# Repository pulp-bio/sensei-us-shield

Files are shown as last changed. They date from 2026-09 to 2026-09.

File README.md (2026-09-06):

# WULPUS PRO Shield for BioGAP

**Wearable, ultra-low-power ultrasound acquisition for the BioGAP-Ultra platform**  
Initial hardware and firmware release: **v1.0.0**

<p align="center">
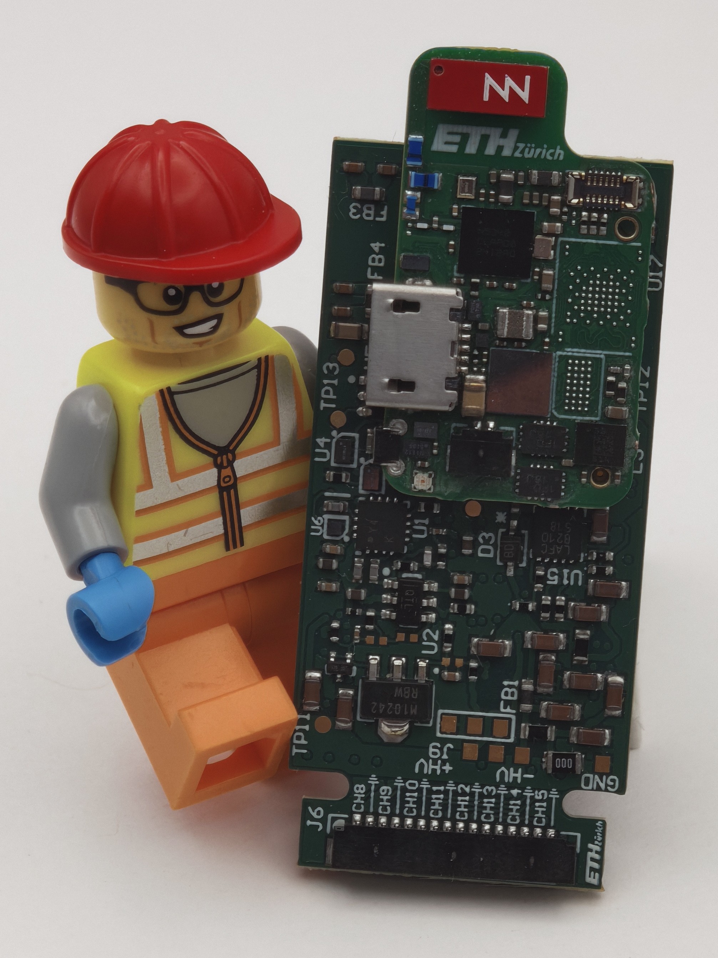
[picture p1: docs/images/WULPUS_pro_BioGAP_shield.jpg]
WULPUS PRO shield for BioGAP-Ultra
  
</p>

The WULPUS PRO shield is a 16-channel, time-multiplexed ultrasound front-end for the [BioGAP-Ultra](https://github.com/pulp-bio/BioGAP) wearable edge-AI platform. It is a successor of the [WULPUS](https://github.com/pulp-bio/wulpus) and [WULPUS-pro](https://github.com/pulp-bio/wulpus-pro) projects and combines high-voltage pulse generation, transmit/receive channel selection, a programmable receive chain, and an MSP430FR5043 ultrasound controller on a compact BioGAP-compatible shield.

This repository contains the **shield hardware** and **MSP430 firmware**. A complete acquisition system also requires compatible BioGAP host firmware and [BioGUI](https://github.com/pulp-bio/biogui), which is the intended desktop application for configuring, visualizing, and recording ultrasound data.

## System Overview

| Component | Responsibility |
| --- | --- |
| **WULPUS PRO shield** | Generates ultrasound pulses, selects transmit/receive channels, conditions echoes, digitizes samples, and exchanges configuration/data with the host over SPI. |
| **BioGAP-Ultra mainboard** | Controls the shield, packages acquired frames, and provides the BLE data link to the host computer. BioGAP-side firmware is maintained in the [BioGAP repository](https://github.com/pulp-bio/BioGAP). |
| **BioGUI** | Provides the BioGAP-Ultra/WULPUS PRO interface, acquisition configuration, live visualization, decoding, and data recording. It is maintained in the [BioGUI](https://github.com/pulp-bio/biogui) repository. |

Configuration flows from BioGUI through BioGAP to the shield. Acquired samples return from the shield over SPI, are transported by BioGAP over BLE, and are reconstructed and displayed by BioGUI.

## Key Features

- **16 time-multiplexed ultrasound channels** for A-mode acquisition.
- **30 V unipolar excitation** with runtime-programmable pulse frequency.
- Support for **piezoelectric and CMUT transducers**, including direct and indirect CMUT biasing in the ±30 V range.
- Low-noise receive path with **up to 70 dB total gain** and programmable time-gain compensation.
- Integrated **12-bit ADC at up to 8 MS/s**.
- MSP430-controlled power domains for the preamplifier, VGA, filter, envelope detector, high-voltage supply, multiplexer, and pulser.
- Standard BioGAP shield connectors for power, SPI, ready/data-ready signaling, and MSP430 programming.

## Repository Structure

| Path | Contents |
| --- | --- |
| [`hardware/`](hardware/) | Altium sources, component libraries, and released manufacturing files for the shield. |
| [`hardware/wulpus_pro_shield/docs/`](hardware/wulpus_pro_shield/docs/) | Schematic and assembly PDFs, BOM, Gerber files, NC drill files, and pick-and-place output. |
| [`firmware/`](firmware/) | MSP430FR5043 firmware project and firmware-specific documentation. |
| [`docs/images/`](docs/images/) | Product photographs and PCB renders used in the documentation. |
| [`CHANGELOG.md`](CHANGELOG.md) | Repository-level release history. |

## Requirements

### Hardware

- A BioGAP-Ultra mainboard and compatible debug/programming hardware.
- An assembled WULPUS PRO shield.
- A compatible piezoelectric or CMUT transducer/array.
- An MSP-FET-compatible programming connection for the MSP430FR5043.

### Software

- A compatible release of the [BioGAP firmware](https://github.com/pulp-bio/BioGAP) with WULPUS PRO support.
- [TI Code Composer Studio](https://www.ti.com/tool/CCSTUDIO) with MSP430 support.
- [BioGUI](https://github.com/pulp-bio/biogui) on the host computer.

## Getting Started

### 1. Manufacture the PCB

Open [`hardware/wulpus_pro_shield/wulpus_pro_shield.PrjPcb`](hardware/wulpus_pro_shield/wulpus_pro_shield.PrjPcb) in Altium Designer to inspect or modify the design. Released manufacturing outputs are under [`hardware/wulpus_pro_shield/docs/`](hardware/wulpus_pro_shield/docs/):

- `BOM/` — bill of materials.
- `Gerber/` — copper, mask, silkscreen, paste, and outline layers.
- `NC Drill/` — drill output.
- `Pick Place/` — component placement data.
- `WULPUS_pro_schematics.PDF` and `WULPUS_pro_shield_assembly.PDF` — review documents.

Review the fabrication package with the PCB manufacturer and assembler before ordering. See [`hardware/README.md`](hardware/README.md) for details.

### 2. Build and Flash the MSP430 Firmware

The project in [`firmware/wulpus_msp430_firmware/`](firmware/wulpus_msp430_firmware/) targets the MSP430FR5043 and was created with Code Composer Studio.

1. Install Code Composer Studio with MSP430 device support.
2. Import `firmware/wulpus_msp430_firmware` as an existing CCS project.
3. Select the **Debug** or **Release** build configuration and build the project.
4. With system power disconnected, connect the MSP-FET programmer to the MSP430 programming interface.
5. Power the assembled system and program the generated `wulpus_msp430_firmware.out` image.

### 3. Flash the BioGAP Mainboard

Build and flash the WULPUS PRO-compatible nRF5340 application from the [BioGAP firmware repository](https://github.com/pulp-bio/BioGAP).

Keep the BioGAP firmware and BioGUI interface versions aligned; their packet format must match.

### 4. Assemble the Stack

1. Disconnect all power and programmers.
2. Check the shield and mainboard connector orientation against the assembly drawings.
3. Plug the WULPUS PRO shield on the BioGAP-Ultra connectors.
4. Connect the transducer or array to the intended channel connector.

### 5. Acquire Data with BioGUI

Install and start BioGUI:

```bash
git clone https://github.com/pulp-bio/biogui.git
cd biogui
uv sync
uv run main.py
```

In BioGUI:

1. Select the **BioGAP-Ultra + WULPUS PRO** board interface. The corresponding implementation is `biogui/platforms/wulpus_pro/interface_biogapultra_wulpus_pro.py`.
2. Connect to the BioGAP device.
3. Configure the transmit/receive channel sequence, pulse settings, acquisition period, sample count, receive gain/time-gain compensation, and optional envelope detector.
4. Start acquisition, verify the live ultrasound trace, and enable recording when required.

With the default firmware configuration, each shield frame contains a 4-byte header followed by 400 16-bit samples.

## Related Projects

- [BioGAP-Ultra](https://github.com/pulp-bio/BioGAP) — mainboard hardware and host firmware.
- [BioGUI](https://github.com/pulp-bio/biogui) — acquisition, visualization, and recording software.
- [WULPUS](https://github.com/pulp-bio/wulpus) — predecessor platform and MSP430 toolchain documentation.
- [WULPUS PRO](https://github.com/pulp-bio/wulpus-pro) — predecessor platform and development kit version of wulpus-pro.

## License

- Hardware under [`hardware/`](hardware/) is licensed under the [Solderpad Hardware License v0.51](hardware/LICENSE).
- Images under [`docs/images/`](docs/images/) are licensed under [CC BY 4.0](docs/images/LICENSE).
- Firmware contains sources under their respective file-header licenses, primarily Apache-2.0 and BSD-style terms. See [`firmware/README.md`](firmware/README.md) and the individual source headers.

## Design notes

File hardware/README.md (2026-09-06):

# WULPUS PRO Shield Hardware

This directory contains the Altium design sources and released manufacturing files for revision **1.0.0** of the WULPUS PRO shield for BioGAP-Ultra.

## Project Layout

| Path | Contents |
| --- | --- |
| [`wulpus_pro_shield/wulpus_pro_shield.PrjPcb`](wulpus_pro_shield/wulpus_pro_shield.PrjPcb) | Top-level Altium PCB project. |
| [`wulpus_pro_shield/`](wulpus_pro_shield/) | Schematic sheets, PCB layout, output jobs, harness definitions, and integrated library. |
| [`wulpus_pro_shield/libs/`](wulpus_pro_shield/libs/) | Project-specific schematic symbols, footprints, and 3D models. |
| [`wulpus_pro_shield/docs/`](wulpus_pro_shield/docs/) | Released fabrication and assembly package. |

## Main Hardware Blocks

- **MSP430FR5043** ultrasound controller and 12-bit, 8 MS/s acquisition subsystem.
- **HV2707** 16-channel high-voltage multiplexer.
- **IXDD604** high-voltage pulser driver and MD0100 transmit/receive protection.
- **AD8338** variable-gain amplifier with **TPL0501** digital control for fixed gain or time-gain compensation.
- **LT3463** positive/negative high-voltage supply.
- BioGAP-compatible board-to-board connectors for power, SPI, handshaking, and MSP430 programming.

## Released Manufacturing Files

The release package is under [`wulpus_pro_shield/docs/`](wulpus_pro_shield/docs/):

- `WULPUS_pro_schematics.PDF` — eight-page schematic set.
- `WULPUS_pro_shield_assembly.PDF` — top and bottom assembly drawings.
- `BOM/BOM_WULPUS_pro_BioGAP_shield.xlsx` — bill of materials.
- `Gerber/` — PCB fabrication layers.
- `NC Drill/` — drill files and reports.
- `Pick Place/` — placement data for assembly.

Before ordering boards, confirm that the BOM, placement variant, stack-up, drill data, and Gerber set match the intended assembly. 

## Editing the Design

1. Open `wulpus_pro_shield/wulpus_pro_shield.PrjPcb` in Altium Designer.
2. Compile the project and resolve any missing library references before editing.
3. Regenerate fabrication outputs with the supplied output job after a design change.
4. Record released hardware changes in the repository-level [`CHANGELOG.md`](../CHANGELOG.md).

## License

The PCB design files are licensed under the [Solderpad Hardware License v0.51](LICENSE).

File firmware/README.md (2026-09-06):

# WULPUS PRO MSP430 Firmware

This directory contains the shield-side firmware for the **MSP430FR5043** ultrasound controller mounted on the WULPUS PRO BioGAP shield.

The MSP430 configures ultrasound timing, pulse generation, transmit/receive channel routing, the receive chain, envelope detection, and power domains. It operates as an SPI peripheral: the BioGAP-Ultra nRF5340 sends acquisition settings and receives the completed ultrasound frames.

## Project

The Code Composer Studio project is located at [`wulpus_msp430_firmware/`](wulpus_msp430_firmware/). Its key sources are:

| Path | Purpose |
| --- | --- |
| `main.c` | Configuration reception, acquisition loop, frame headers, and event callbacks. |
| `system_pre_init.c` | MSP430 clock and early-system initialization. |
| `wulpus/us_spi.*` | DMA-backed SPI interface to the BioGAP host. |
| `wulpus/us_hv_mux.*` | 16-channel high-voltage multiplexer control. |
| `wulpus/wulpus_sys.*` | Configuration decoding, GPIO mapping, power control, VGA/TGC, filter, envelope detector, and pulser control. |

## Toolchain and Dependencies

The checked-in project metadata targets:

- TI Code Composer Studio **11.0**.
- TI MSP430 Code Generation Tools **21.6.0.LTS**.
- MSP430FR5043.
- An MSP-FET-compatible programmer/debugger.

The complete repository includes the `driverlib/`, `uslib/`, and `targetConfigs/` directories required by the CCS project. Keep these directories alongside the project sources when cloning, copying, or importing the firmware project.

The upstream [MSP430 toolchain and flashing guide](https://github.com/pulp-bio/wulpus/blob/main/fw/msp430/how_to_setup_msp_430_toolchain_and_flash.md) provides the detailed CCS setup procedure.

## Build and Flash

1. Install Code Composer Studio with **MSP430 ultra-low-power MCU** support.
2. Confirm that the included `driverlib/`, `uslib/`, and `targetConfigs/` directories are present inside `wulpus_msp430_firmware/`.
3. In CCS, select **File → Open Projects from File System** and choose `firmware/wulpus_msp430_firmware`.
4. Select **Project → Build Configurations → Set Active → Debug** or **Release**.
5. Build the project.
6. With power disconnected, attach the MSP-FET-compatible programmer to the shield programming interface.
7. Power the BioGAP/shield stack and program `wulpus_msp430_firmware.out` from CCS.

## BioGAP and BioGUI Integration

The MSP430 firmware is only the shield-side part of the acquisition chain:

1. [BioGUI](https://github.com/pulp-bio/biogui) creates the WULPUS PRO configuration and sends it to BioGAP.
2. BioGAP forwards the configuration to the MSP430 over SPI.
3. The MSP430 acquires the selected transmit/receive sequence and returns an 804-byte frame: a 4-byte header followed by 400 signed 16-bit samples.
4. BioGAP transports the frame over BLE, and BioGUI's `interface_biogapultra_wulpus_pro.py` implementation reassembles, decodes, displays, and records it.

Use a BioGAP firmware revision and BioGUI revision with matching WULPUS PRO packet definitions.

## Release History

See [`wulpus_msp430_firmware/CHANGELOG.md`](wulpus_msp430_firmware/CHANGELOG.md).

## License

The project contains sources under their respective file-header licenses, primarily Apache-2.0 and BSD-style terms. TI DriverLib, USSlib, and other imported dependencies retain their upstream licenses; review the license notices within those directories.

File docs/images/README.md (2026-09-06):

# WULPUS PRO shield Images

This directory contains the images used to document the WULPUS PRO shield for BioGAP-Ultra.

| File | Description |
| --- | --- |
| `WULPUS_pro_BioGAP_shield.jpg` | Product photograph used in the repository README. |
| `WULPUS_pro_BioGAP_shield_top.png` | Top-side PCB. |
| `WULPUS_pro_BioGAP_shield_bottom.png` | Bottom-side PCB. |

## Author

- Sebastian Frey, ETH Zurich.

## License

The images are licensed under the [Creative Commons Attribution 4.0 International License](LICENSE). When reusing an image, credit Sebastian Frey, ETH Zurich, and link to the license.

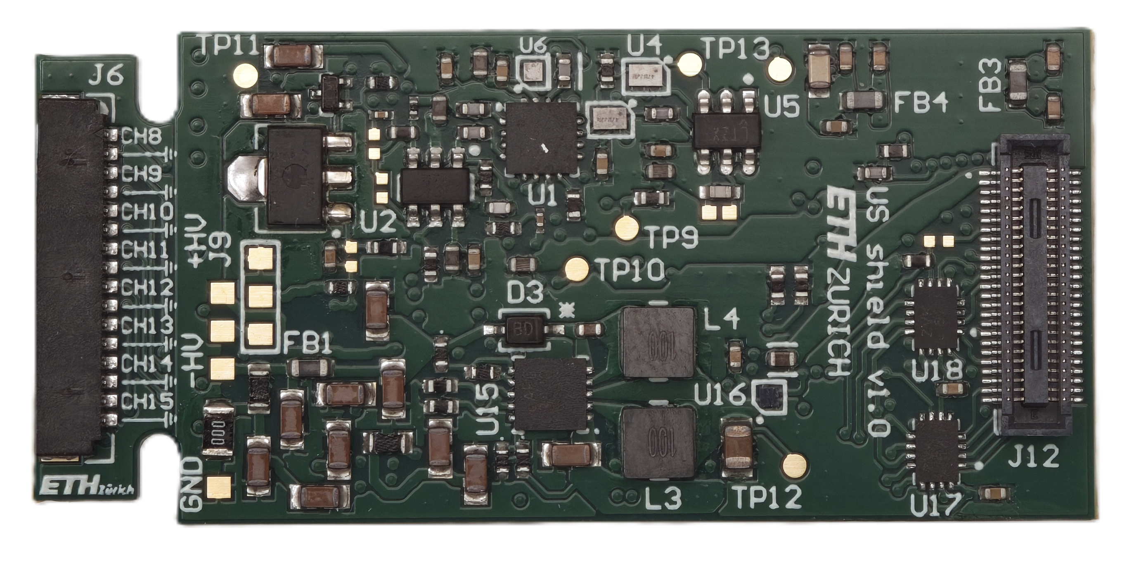
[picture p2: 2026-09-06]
docs/images/WULPUS_pro_BioGAP_shield_bottom.png

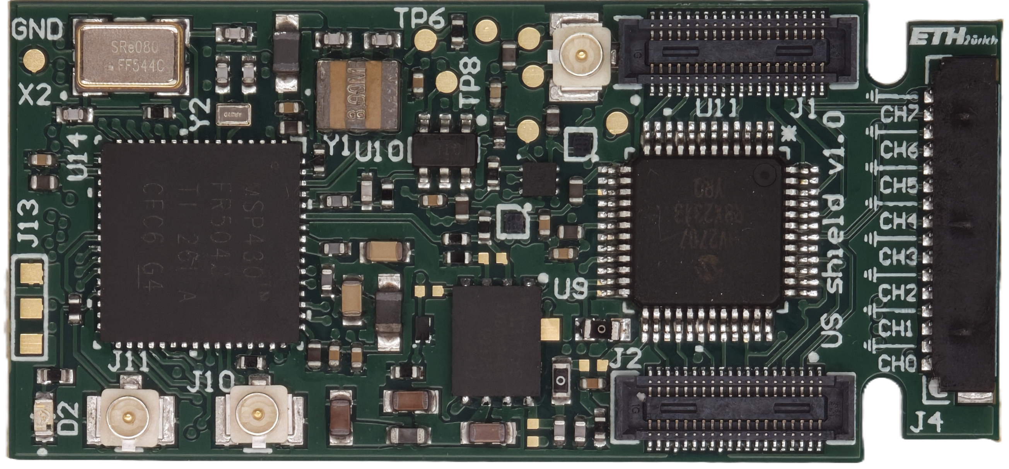
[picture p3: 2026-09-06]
docs/images/WULPUS_pro_BioGAP_shield_top.png

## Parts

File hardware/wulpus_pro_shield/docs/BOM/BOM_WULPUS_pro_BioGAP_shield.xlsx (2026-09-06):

Comment | Quantity | Designator | Description
GJM1555C1H1R5BB01D | 1 | C1 | GJM1555C1H1R5BB01D
C0402C104K4RACTU | 17 | C2, C15, C16, C17, C19, C25, C27, C29, C46, C47, C48, C68, C69, C70, C71, C75, C76 | C0402C104K4RACTU
GRM033R71A103KA01D | 2 | C3, C6 | GRM033R71A103KA01D
GRM1555C1H102JA01D | 8 | C4, C7, C9, C38, C40, C41, C51, C77 | GRM1555C1H102JA01D, Chip Multilayer Ceramic Capacitors for General Purpose, 0402, 1000pF, C0G, 30ppm/°C, 5%, 50V
04025C332JAT2A | 1 | C5 | 04025C332JAT2A
C1005X7S1A225K050BC | 14 | C8, C12, C13, C18, C24, C26, C28, C43, C44, C45, C72, C73, C74, C80 | C1005X7S1A225K050BC
04025A101FAT2A | 2 | C11, C23 | 04025A101FAT2A
GRM188R60J476ME01D | 3 | C14, C39, C42 | GRM188R60J476ME01D
GRM1555C1H100JA01D | 2 | C20, C21 | GRM1555C1H100JA01D
GRM188R61H225ME11D | 7 | C22, C56, C57, C58, C60, C61, C63 | GRM188R61H225ME11D
GRM188R61H225ME11 | 8 | C30, C31, C32, C33, C34, C35, C78, C79 | GRM188R61H225ME11
GRM155R71H473ME14D | 2 | C36, C37 | GRM155R71H473ME14D
GJM1555C1H120GB01D | 6 | C49, C50, C52, C53, C54, C55 | Multi-Layer Ceramic Capacitor 12pF C0G ±2% 0402 Paper T/R
GCM21BR71H105KA03L | 1 | C59 | GCM21BR71H105KA03L
GRM155C71H104KE19D | 1 | C62 | GRM155C71H104KE19D
GRM155Z71A105KE01D | 4 | C64, C65, C66, C67 | GRM155Z71A105KE01D
BAV99T-7-F | 1 | D1 | DIODE ARRAY GP 85V 75MA SOT523
APHD1608LZGCK | 1 | D2 | LED GREEN CLEAR 1608 SMD
ZHCS400QTA | 1 | D3 | Diode Schottky 40V 1A Automotive 2-Pin SOD-323 T/R
BLM18SP101SN1D | 2 | FB1, FB2 | BLM18SP101SN1D Ferrite Bead, 100 Ohm, 3.7A, 0603 Rohs Compliant: Yes
BLM18SP101SH1D | 2 | FB3, FB4 | BLM18SP101SH1D Ferrite Beads Multi-Layer 100Ohm 25% 100MHz 3.7A 0.022Ohm DCR 0603 Automotive T/R
DF40C-40DS-0.4V(51) | 2 | J1, J2 | CONN RCPT 40POS SMD GOLD
DF52-16S-0.8H(21) | 2 | J4, J6 | No Description Available
U.FL-R-SMT-1(10) | 3 | J10, J11, J15 | CONN U.FL RCPT STR 50 OHM SMD
DF40HC(3.0)-50DS-0.4V(51) | 1 | J12 | 50 Position 0.4mm Pitch Dual Row Vertical Surface Mount (SMT) Pin Socket, 3.0mm Stacking Height
742792040 | 2 | L1, L2 | SMD EMI Suppression Ferrite Bead WE-CBF, Z = 600 Ohm
LQH3NPZ100MMEL | 2 | L3, L4 | Wire Wound Ferrite Inductor for Power Lines For Automotive 10μH ±20% 0.228Ω 1280mA 1212
NX7002BKMBYL | 1 | Q1 | MOSFET (N-Channel)
CRCW04021K30JNED | 1 | R1 | CRCW04021K30JNED
ERJ-2RKF2001X | 2 | R2, R3 | ERJ-2RKF2001X
CRCW04021R00FKEDC | 1 | R4 | CRCW04021R00FKEDC
MCS04020C2701FE000 | 1 | R5 | MCS04020C2701FE000
CRCW04020000Z0ED | 3 | R8, R18, R46 | CRCW04020000Z0ED
RMCF0201JT47K0 | 1 | R9 | RMCF0201JT47K0
CRCW040210K0JNED | 8 | R10, R11, R12, R14, R16, R22, R43, R44 | CRCW040210K0JNED
CRCW040251R0JNED | 1 | R13 | CRCW040251R0JNED
ERJ-3GEY0R00V | 1 | R15 | ERJ-3GEY0R00V
CRCW0402402RFKEDC | 2 | R21, R34 | CRCW0402402RFKEDC
ERJ-PA3J302V | 2 | R23, R24 | Resistor, ERJ-PA3J302V
RC1005F394CS | 2 | R26, R29 | RC1005F394CS
ERJ-2RKF1003X | 2 | R27, R28 | ERJ-2RKF1003X
CRCW04021M00FKED | 2 | R31, R32 | RES Thick Film, 1MΩ, 1%, 0.063W, 100ppm/°C, 0402
RC0402JR-0722RL | 3 | R33, R35, R38 | RC0402JR-0722RL, [NoValue]
CPF0402B324RE1 | 1 | R36
CRCW040247K0FKED | 1 | R37 | RES Thick Film, 47kΩ, 1%, 0.063W, 100ppm/°C, 0402
ERJ-2RKF1004X | 2 | R39, R42 | ERJ-2RKF1004X
ERJ-2RKF4322X | 1 | R40 | ERJ-2RKF4322X
ERJ-2RKF4122X | 1 | R41 | ERJ-2RKF4122X
AD8338ACPZ-R7 | 1 | U1 | IC OPAMP VGA 1 CIRCUIT 16LFCSP
OPA836IDBVT | 2 | U2, U10 | Very Low Power, Rail to Rail Out, Negative Rail In, VFB Operational Amplifier, 2.5 to 5.5 V, -40 to 125 degC, 6-pin SOT23 (DBV6), Green (RoHS & no Sb/Br)
TPL0501-100RSER | 1 | U3 | 256-Tap, 100 k, Single Channel Potentiometer with SPI Interface, -40 to 125 degC, 8-pin QFN (RSE8), Green (RoHS & no Sb/Br)
TS5A3159AYZPR | 2 | U4, U7 | Analogue Switch ICs SPDT ANALOG SWITCH
LTC5507ES6#TRMPBF | 1 | U5 | IC RF DETECT 100KHZ-1GHZ TSOT23
TPS22916CYFPR | 4 | U6, U8, U12, U16 | TPS22916 5.5-V, 2-A Ultra-Low Leakage Load Switch
IXDD604D2TR | 1 | U9 | Integrated Circuit
HV2707T-C/R8X | 1 | U11 | 16-CH 200V No Hv Bias Switch (SPST), 2 Bleed Resistor 48 LQFP 7X7X1.4MM T/r Rohs Compliant: Yes
MD0100 | 1 | U13
MSP430FR5043IRGCT | 1 | U14 | No Description Available
LT3463EDD#PBF | 1 | U15 | Dual Micropower DC/DC Converters with Schottky Diodes, 2.4 to 15 V Vin, 10-pin SON (DD-10), -40 to 85 degC, Pb-Free
SN74AVC4T774RSVR | 2 | U17, U18 | Voltage Level Translator Bidirectional 1 Circuit 4 Channel 380Mbps 16-UQFN _2.6x1.8_
FY0800018 | 1 | X2 | Crystal 8MHz ±30ppm (Tol) ±30ppm (Stability) 18pF FUND 100Ohm 4-Pin SMD T/R
AWSCR-8.00CV-T | 1 | Y1 | No Description Available
ABS05-32.768KHZ-9-T | 1 | Y2 | CRYSTAL 32.7680KHZ 9PF SMD

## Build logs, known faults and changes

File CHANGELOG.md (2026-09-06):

# Changelog

All notable changes to this project are documented in this file. The format is based on [Keep a Changelog](https://keepachangelog.com/en/1.1.0/), and version numbers follow [Semantic Versioning](https://semver.org/spec/v2.0.0.html).

## [Unreleased]

## [1.0.0] - 2026-09-04

### Added

- Initial WULPUS PRO ultrasound shield release for BioGAP-Ultra.
- Altium design sources and released schematic, assembly, BOM, Gerber, drill, and pick-and-place files.
- MSP430FR5043 firmware for 16-channel ultrasound control, acquisition, and BioGAP host communication.
- Runtime control of the pulser, high-voltage multiplexer, receive path, time-gain compensation, envelope detector, and power domains.
- BioGUI acquisition workflow and dedicated BioGAP-Ultra/WULPUS PRO interface documentation.

[1.0.0]: https://github.com/pulp-bio/sensei-us-shield/releases/tag/v1.0.0

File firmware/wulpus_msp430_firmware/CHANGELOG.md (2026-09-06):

# Changelog

All notable MSP430 firmware changes are documented here. The format is based on [Keep a Changelog](https://keepachangelog.com/en/1.1.0/), and version numbers follow [Semantic Versioning](https://semver.org/spec/v2.0.0.html).

## [1.0.0] - 2026-09-04

### Added

- Initial WULPUS PRO shield firmware, derived from the WULPUS-pro MSP430 firmware.
- BioGAP host configuration and 804-byte SPI frame transfer with a 4-byte header and 400 16-bit samples.
- GPIO control for the preamplifier, VGA, low-pass filter, envelope detector, high-voltage converters, high-voltage multiplexer, and pulser.
- VGA RC precharge timing and gain-slope wiper configuration for fixed-gain and time-gain-compensation modes.
- Dedicated timer support for precise VGA precharge control.

### Changed

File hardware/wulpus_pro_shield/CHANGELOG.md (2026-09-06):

# Hardware Changelog

All notable changes to the WULPUS PRO shield PCB are documented in this file. The format is based on [Keep a Changelog](https://keepachangelog.com/en/1.1.0/).

## [Unreleased]

## [1.0.0] - 2026-09-04

### Added

* Initial WULPUS PRO shield PCB release for the BioGAP platform.
* 16-channel high-voltage multiplexer and transmit/receive protection.
* 30 V ultrasound pulser.
* Programmable receive chain with preamplifier, variable-gain amplification, and low-pass filtering.
* 12-bit, 8 MS/s ultrasound acquisition.
* Positive and negative high-voltage supplies supporting piezoelectric and CMUT transducers.
* BioGAP power, SPI, handshake, and MSP430 programming interfaces.
* Altium design sources and component libraries.
* Manufacturing files, including schematics, assembly drawings, BOM, Gerber files, NC drill files, and pick-and-place data.

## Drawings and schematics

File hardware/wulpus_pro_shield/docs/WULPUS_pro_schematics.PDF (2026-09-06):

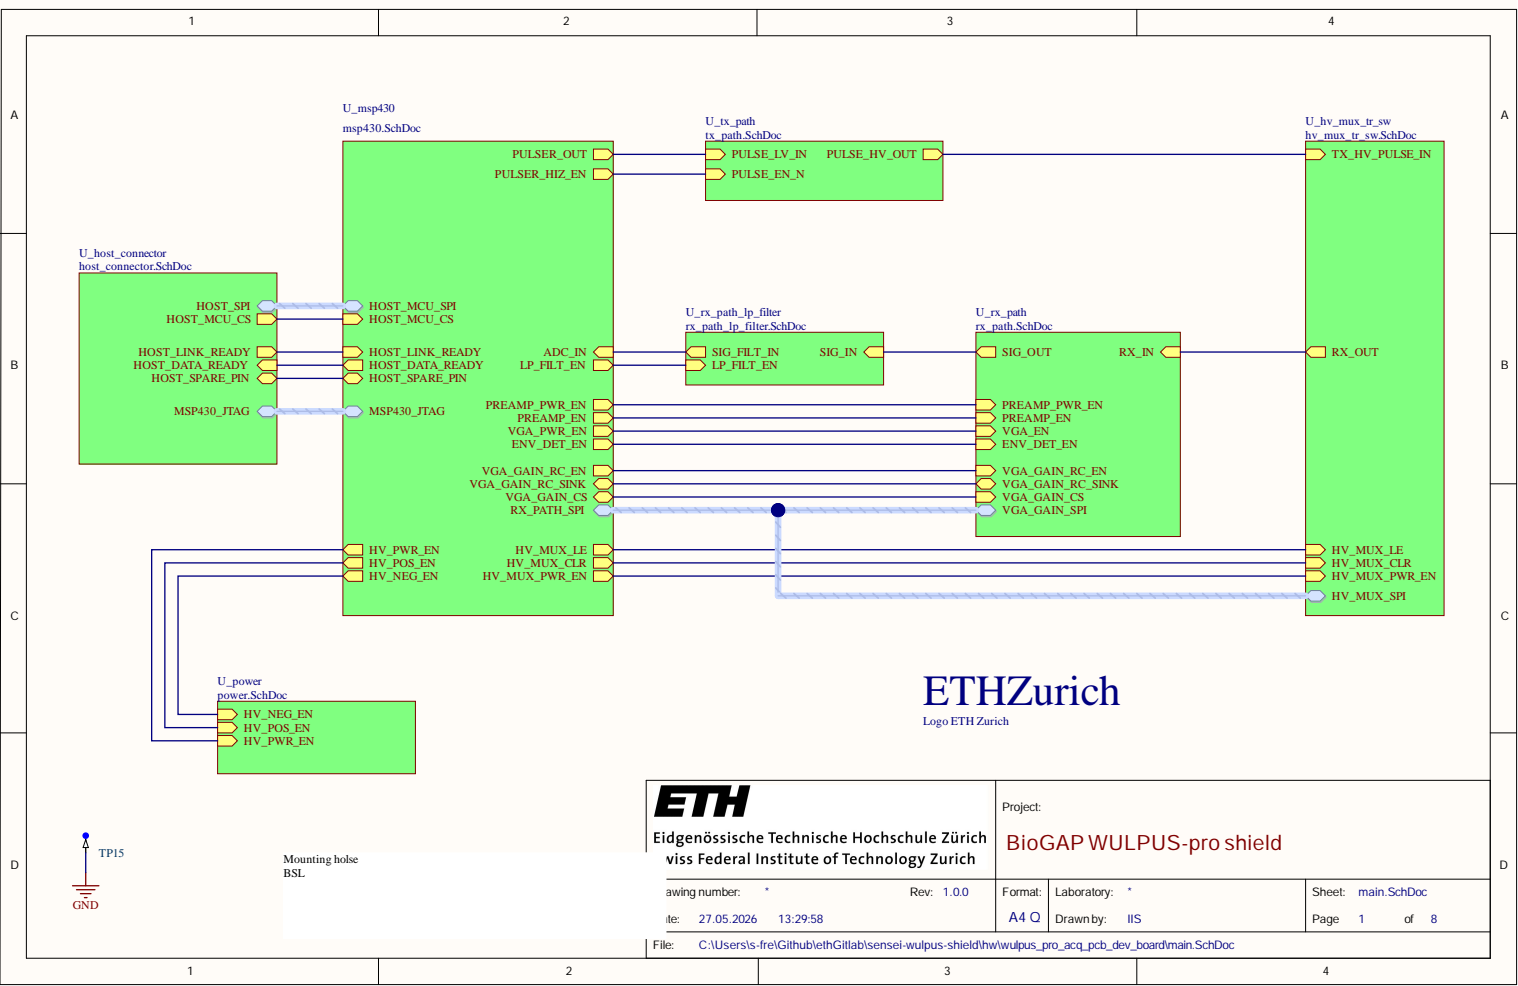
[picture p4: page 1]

Proje c t: B i o G A P W U L P U S -p ro s h i e l d

Drawing num D a | b e r: * R e v : 1. 0. 0 te : 27.05. 202 6 13:29 : 58 | Form a t: A 4 Q | Laborato ry : * Drawn by : I I S | Shee t: main. S c h D o c Pag e 1 of 8

\s-fre\Github\ethGitlab\sensei-wulpus-shield\hw\wu
sers

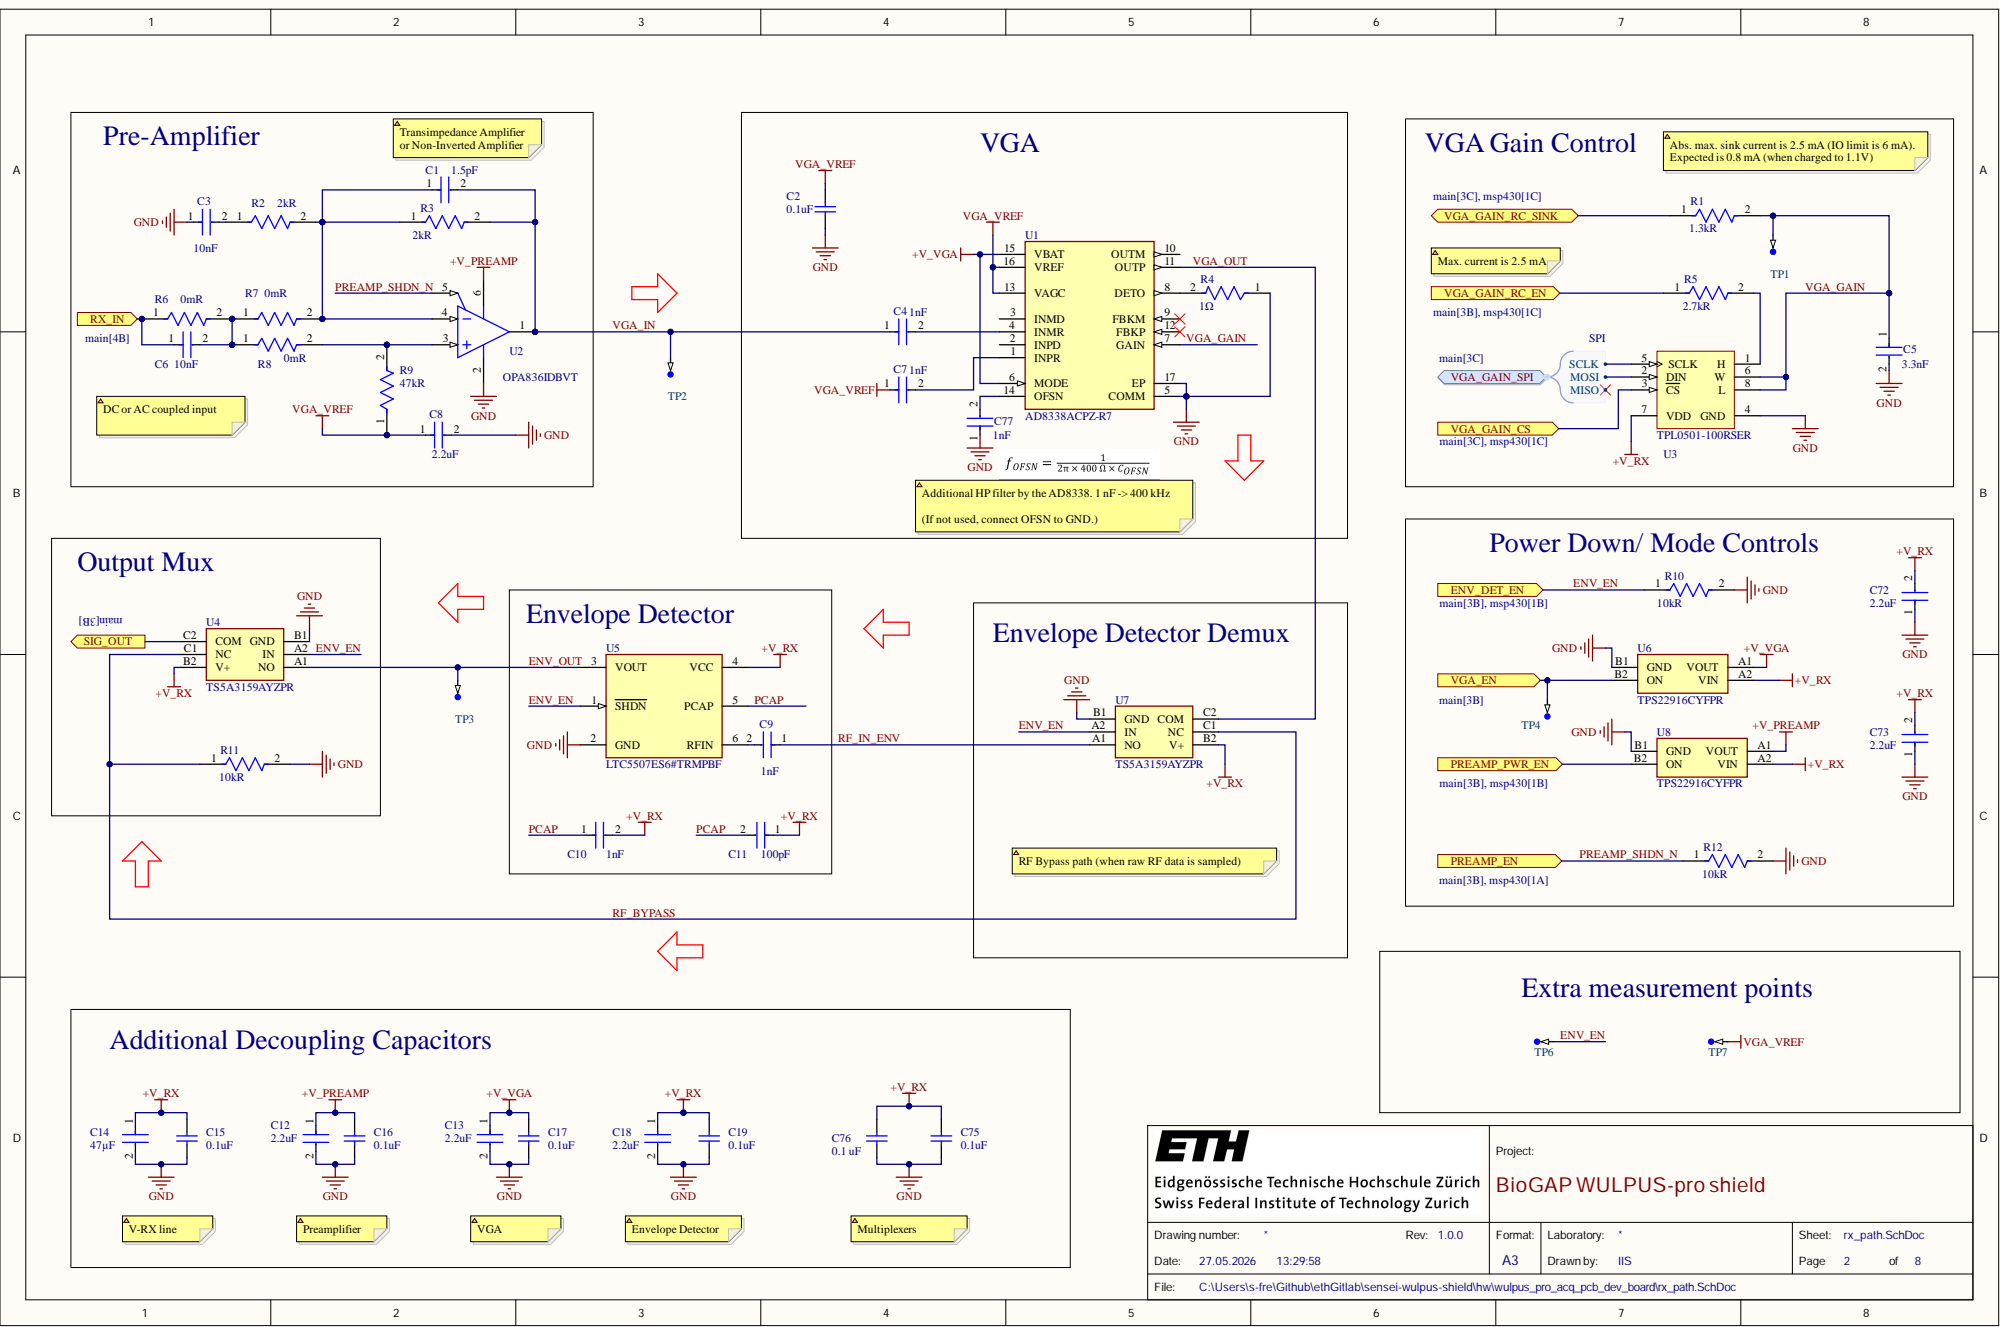
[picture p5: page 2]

Expected is 0.8 mA (when charged to 1.1V)

Max. current is 2.5 mA

MODE 6

DC or AC coupled input

VDD 7

Additional HP filter by the AD8338. 1 nF -> 400 kHz

(If not used, connect OFSN to GND.)

Power Down/ Mode Controls

RF Bypass path (when raw RF data is sampled)

Project: BioGAP WULPUS-pro shield

Drawing number: * Rev: 1.0.0 Date: 27.05.2026 13:29:58 | Format: A3 | Laboratory: * Drawn by: IIS | Sheet: rx_path.SchDoc Page 2 of 8

C:\Users\s-fre\Github\ethGitlab\sensei-wulpus-shield\hw\wulpus_pro_acq_pcb_dev_board\rx_path.SchDoc

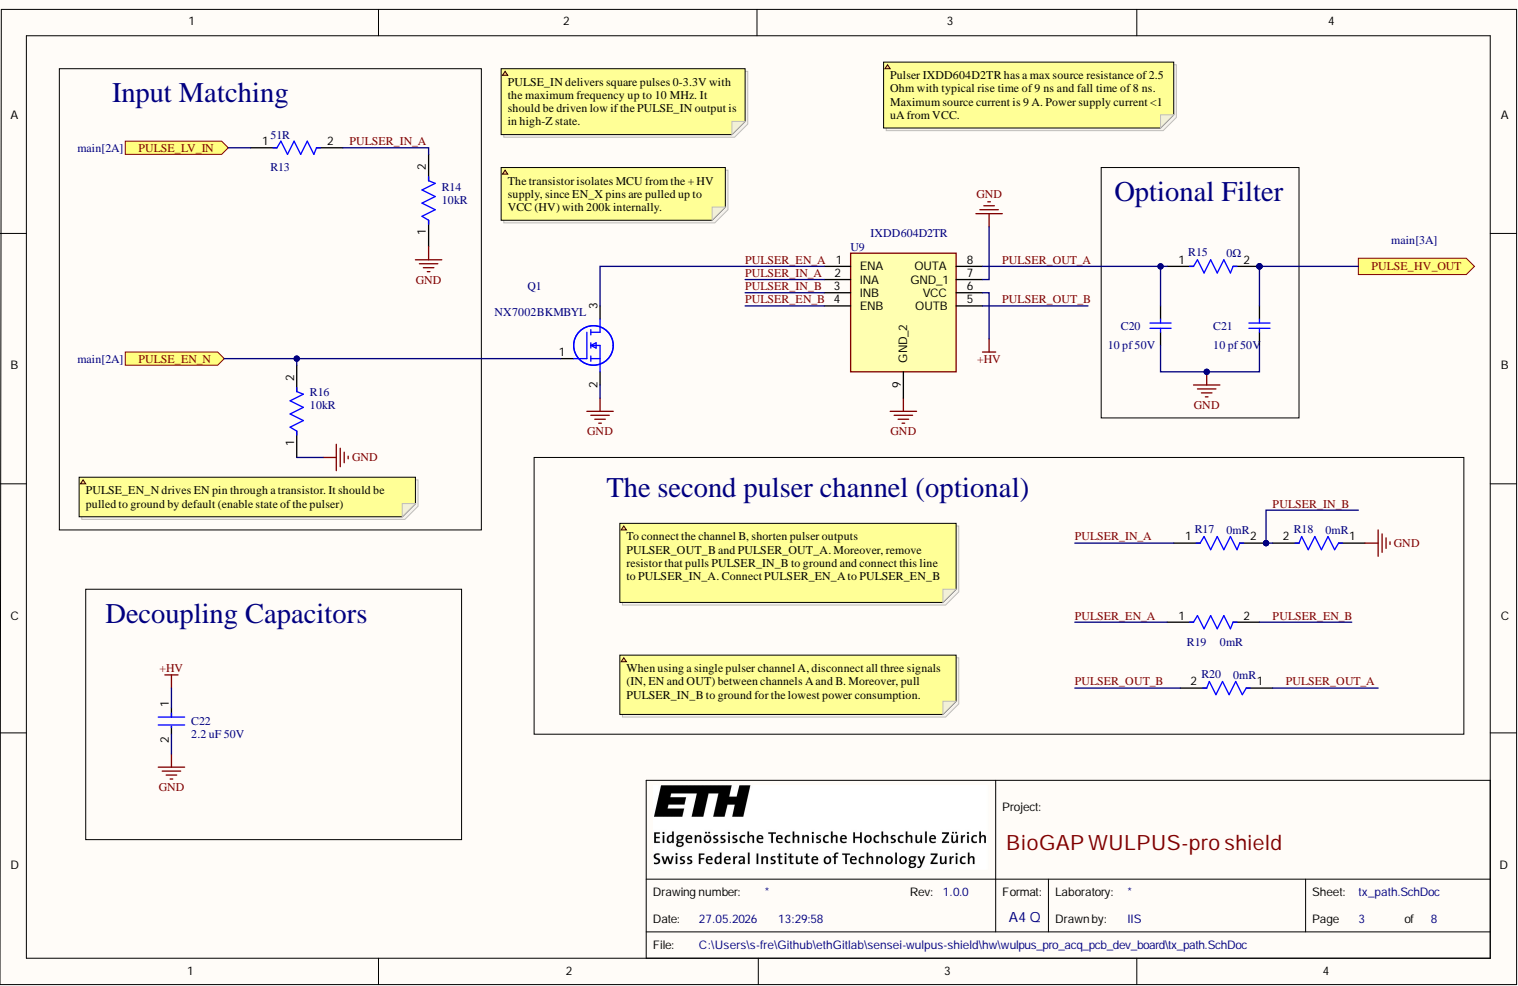
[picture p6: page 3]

PULSE_IN deliverssquare pulses 0-3.3V with
the maximum frequency up to 10 MHz. It
should be driven low if the PULSE_IN output is
in high-Z state.

Pulser IXDD604D2TR has a max source resistance of 2.5
Ohm with typical rise time of 9 ns and fall time of 8 ns.
Maximum source current is 9 A. Power supply current <1
uA from VCC.

The transistor isolates MCU from the + HV
supply, since EN_X pins are pulled up to
VCC (HV) with 200k internally.

PULSE_EN_N drives EN pin through a transistor. It should be
pulled to ground by default (enable state of the pulser)

The second pulser channel (optional)

To connect the channel B, shorten pulser outputs
PULSER_OUT_B and PULSER_OUT_A. Moreover, remove
resistor that pulls PULSER_IN_B to ground and connect this line
to PULSER_IN_A. Connect PULSER_EN_A to PULSER_EN_B

When using a single pulser channel A, disconnect all three signals
(IN, EN and OUT) between channels A and B. Moreover, pull
PULSER_IN_B to ground for the lowest power consumption.

Project: BioGAP WULPUS-pro shield

Drawing number: * Rev: 1.0.0 | Format: A4 Q | Laboratory: * | Sheet: tx_path.SchDoc Page 3 of 8

C:\Users\s-fre\Github\ethGitlab\sensei-wulpus-shield\hw\wulpus_pro_acq_pcb_dev_board\tx_path.SchDoc

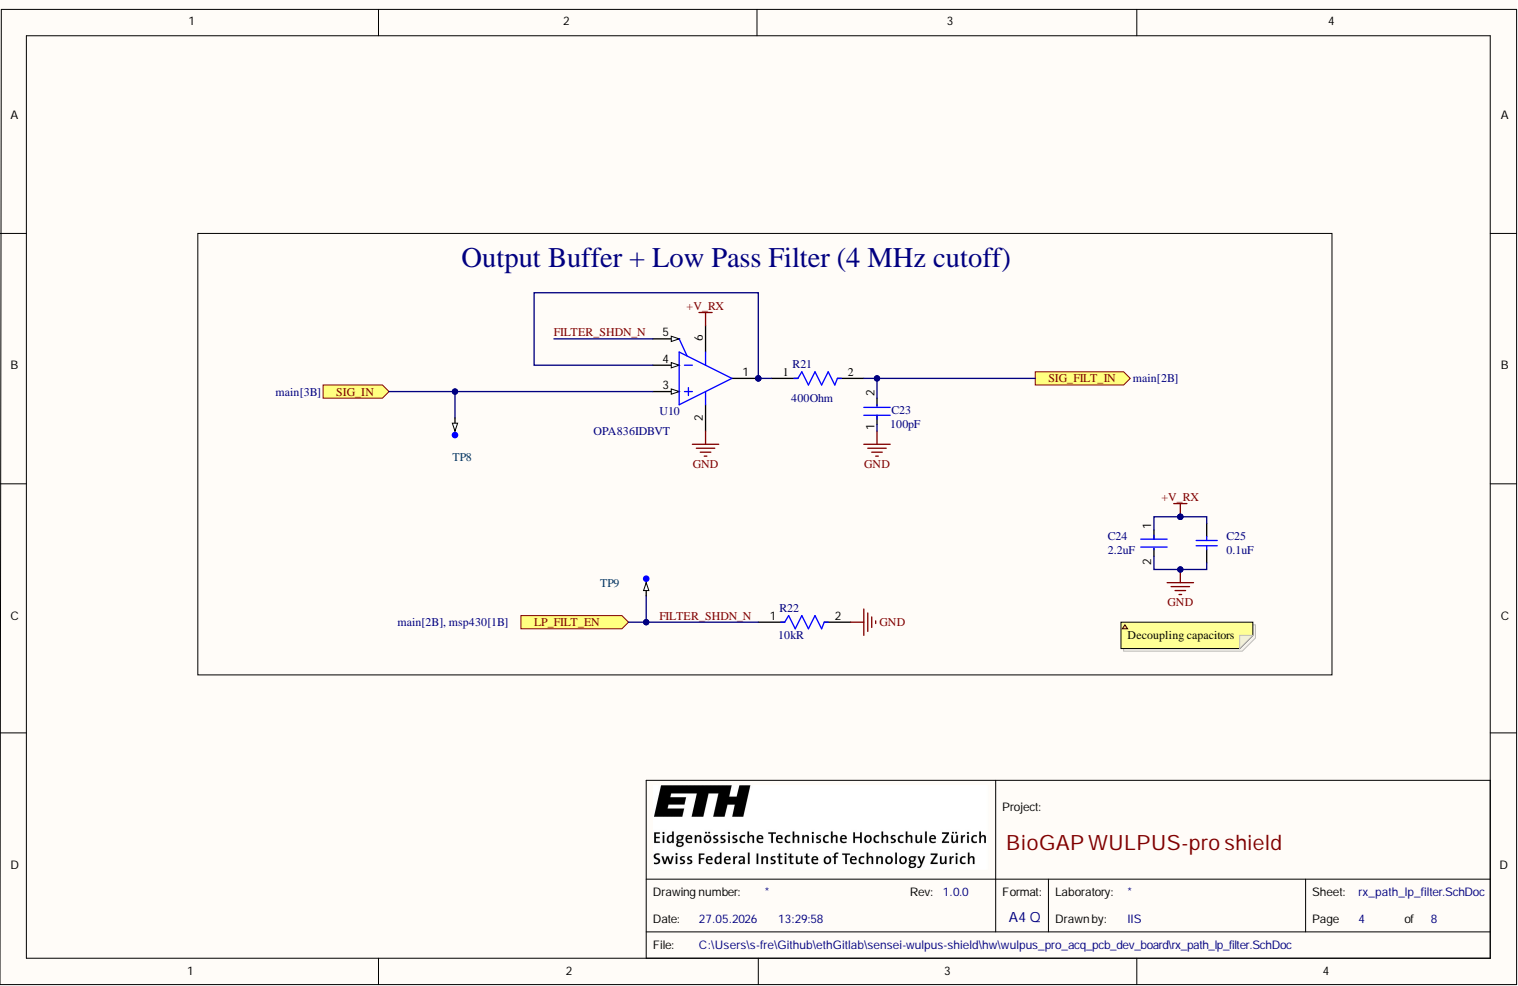
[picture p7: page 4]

Output Buffer + Low Pass Filter (4 MHz cutoff)

Project: BioGAP WULPUS-pro shield

Drawing number: * Rev: 1.0.0 | Format: A4 Q | Laboratory: * | Sheet: rx_path_lp_filter.SchDoc Page 4 of 8

C:\Users\s-fre\Github\ethGitlab\sensei-wulpus-shield\hw\wulpus_pro_acq_pcb_dev_board\rx_path_lp_filter.SchDoc

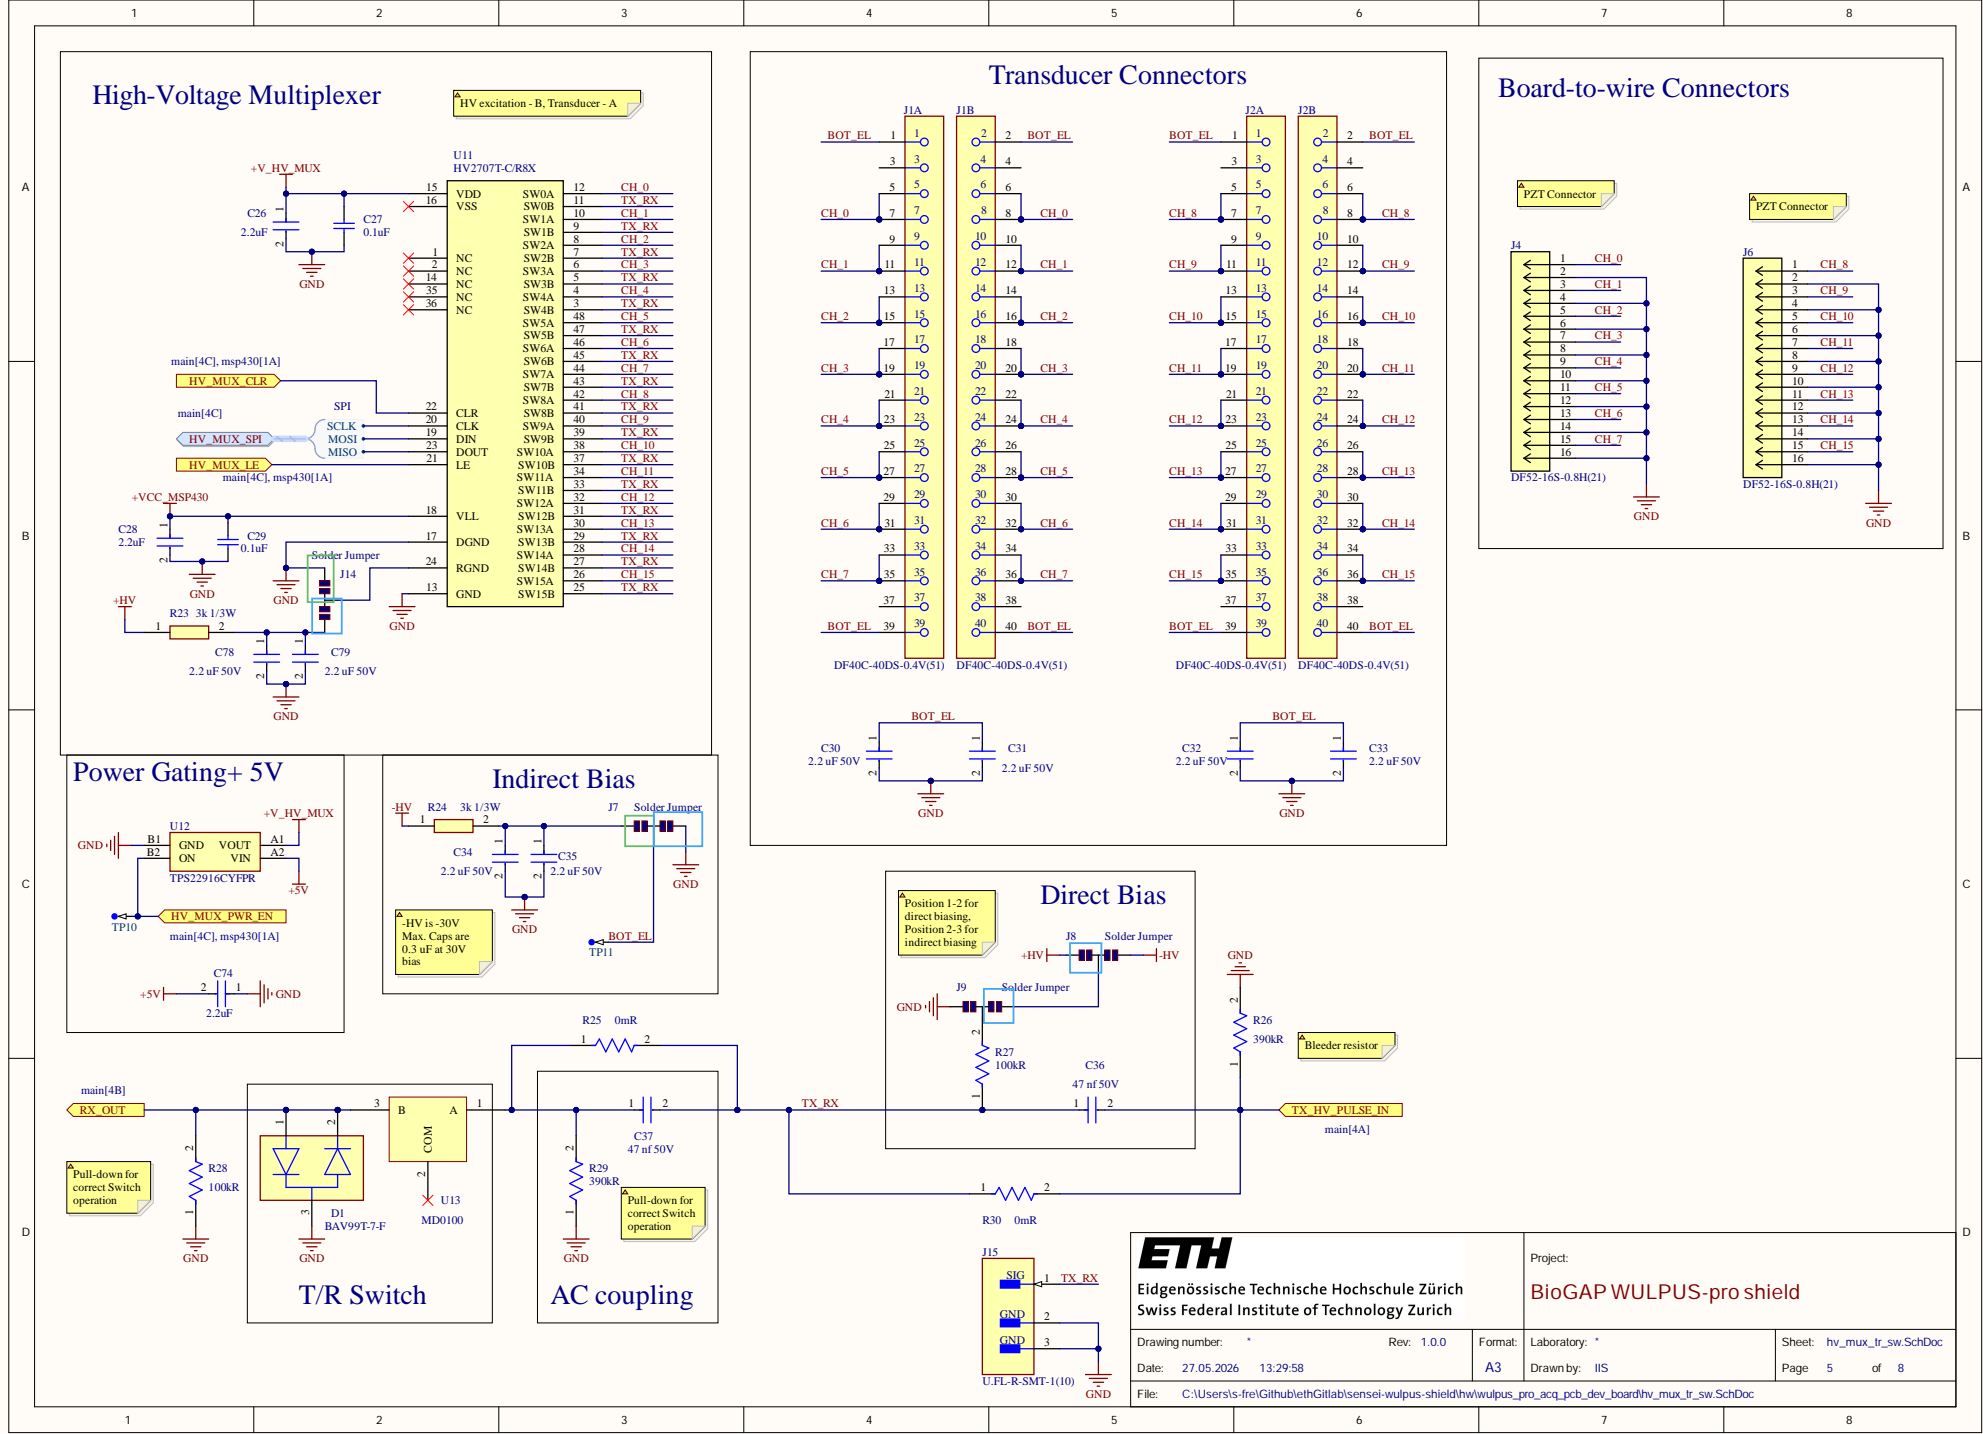
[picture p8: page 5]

Project:
BioGAP WULPUS-pro shield

C:\Users\s-fre\Github\ethGitlab\sensei-wulpus-shield\hw\wulpus_pro_acq_pcb_dev_board\hv_mux_tr_sw.SchDoc

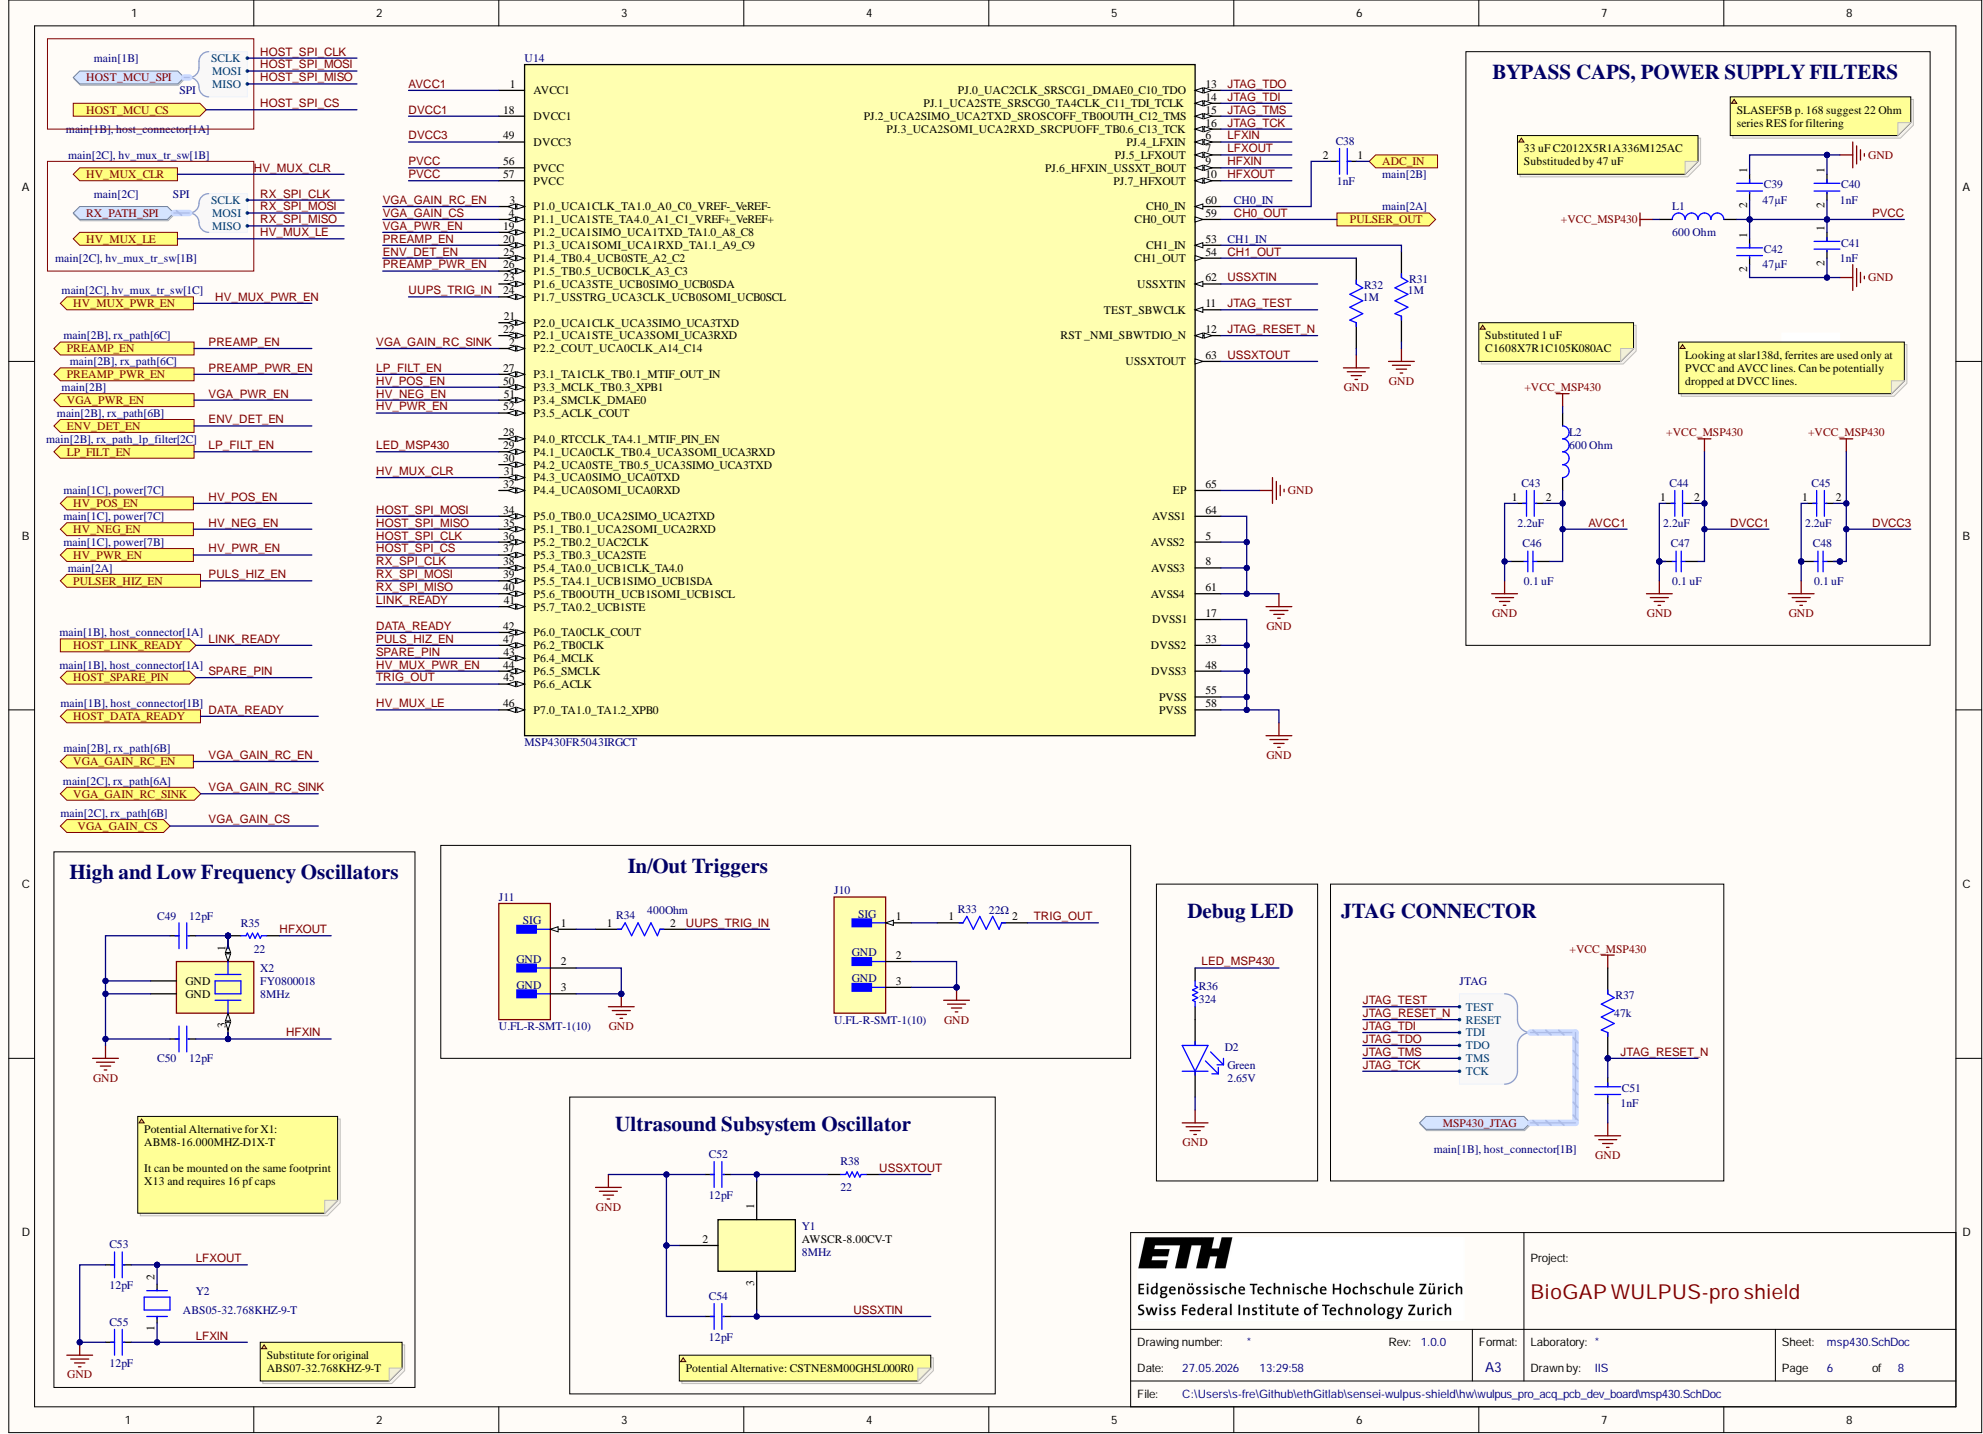
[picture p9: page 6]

BYPASS CAPS, POWER SUPPLY FILTERS

SLASEF5B p. 168 suggest 22 Ohm
series RES for filtering

PVCC and AVCC lines. Can be potentially
dropped at DVCC lines.

High and Low Frequency Oscillators

It can be mounted on the same footprint
X13 and requires 16 pf caps

Project: BioGAP WULPUS-pro shield

msp430.SchDoc Page 6 of 8

C:\Users\s-fre\Github\ethGitlab\sensei-wulpus-shield\hw\wulpus_pro_acq_pcb_dev_board\msp430.SchDoc

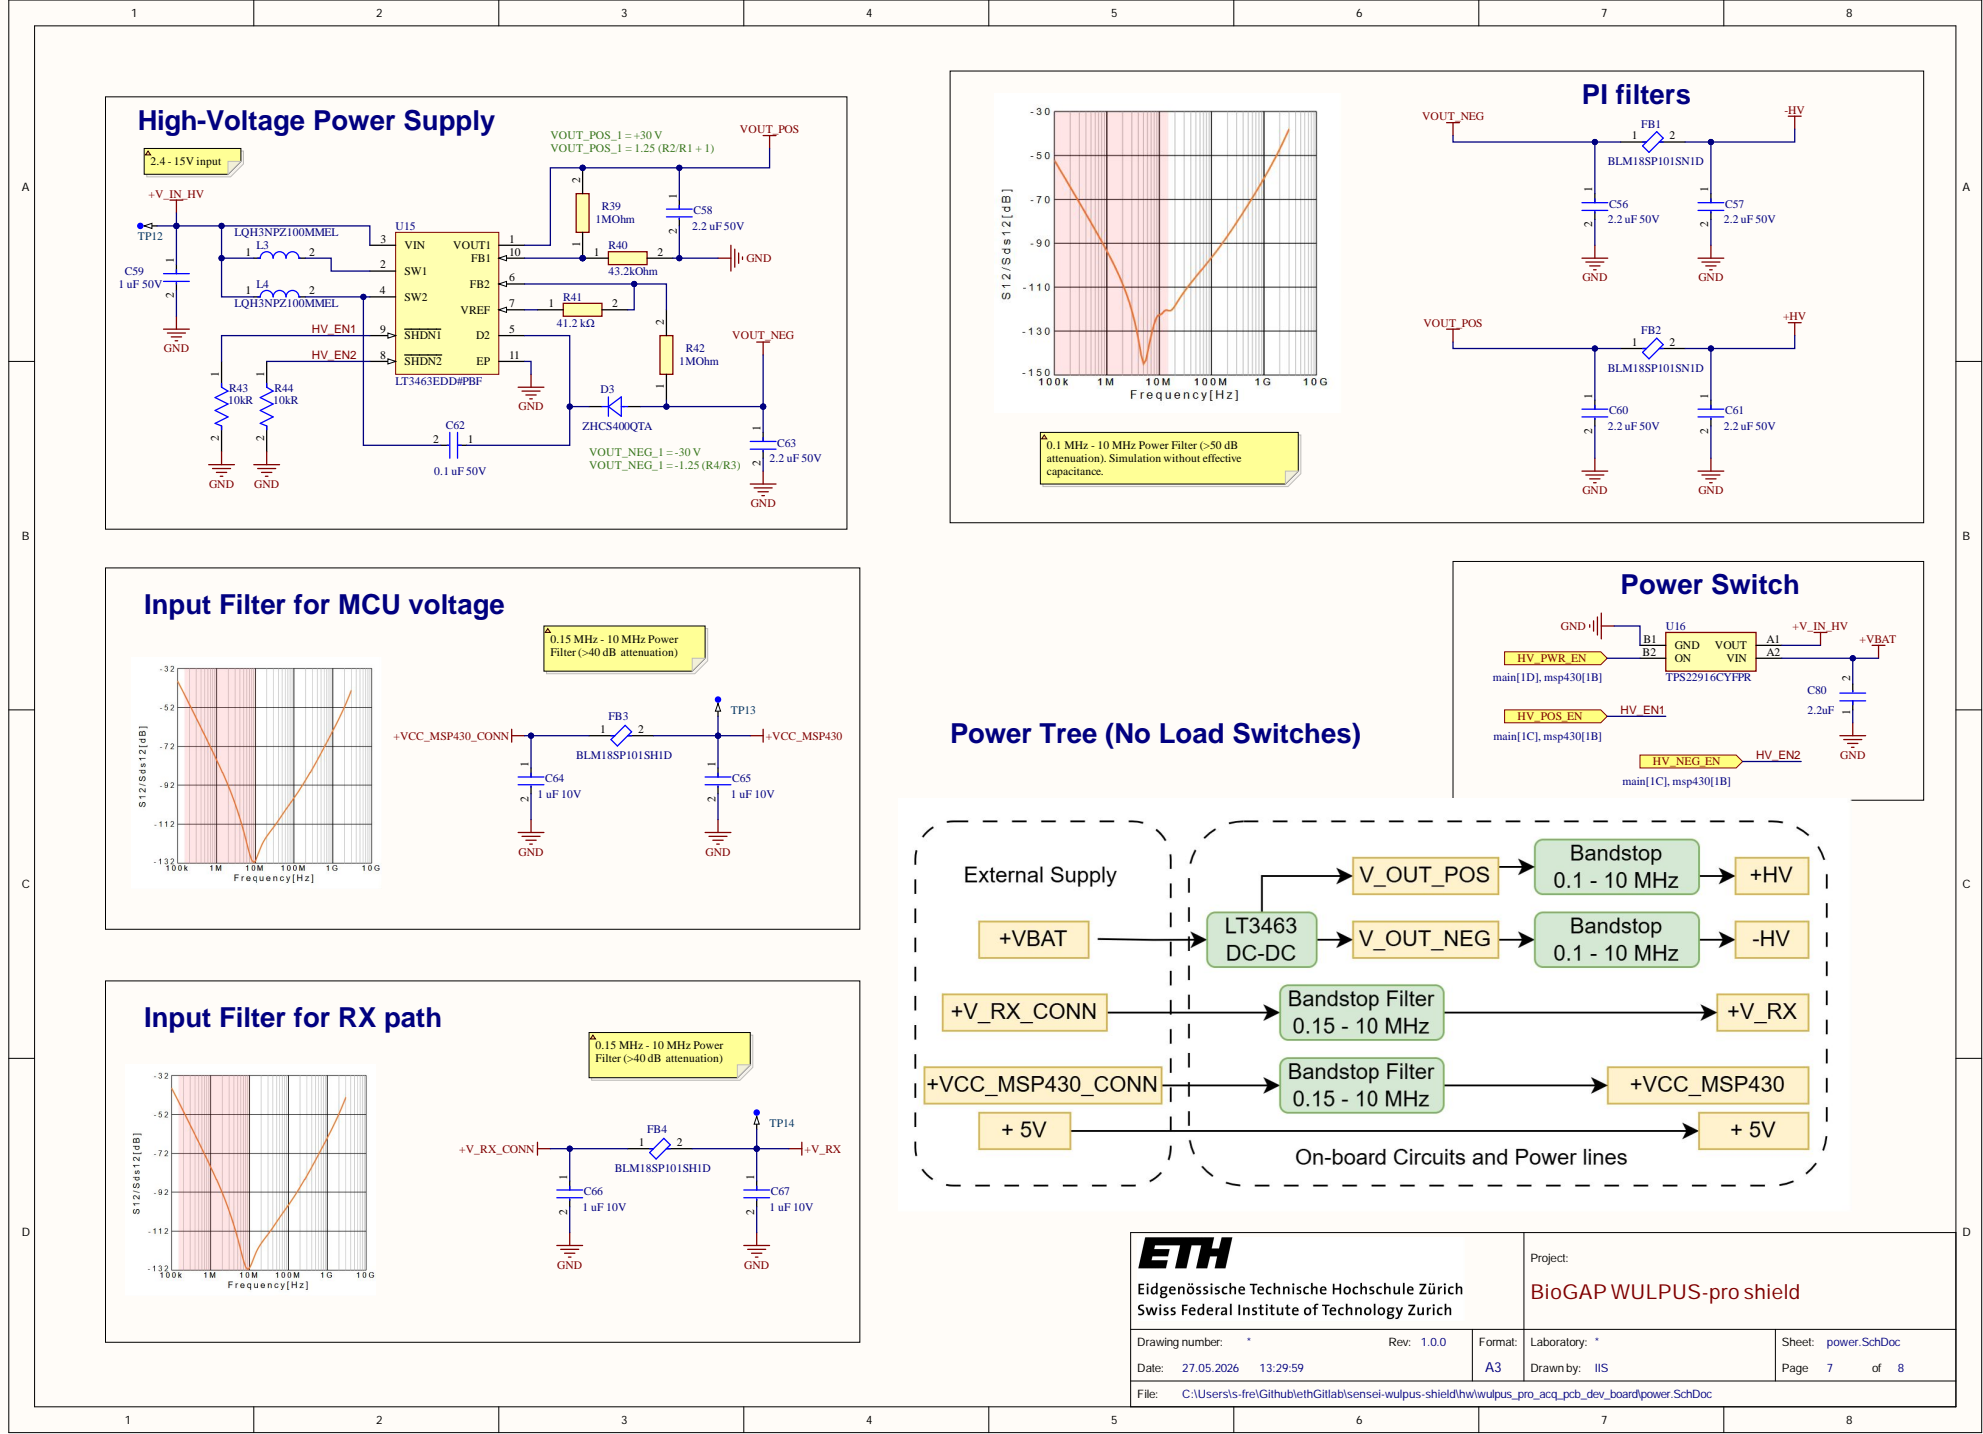
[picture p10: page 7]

High-Voltage Power Supply

SHDN1 9

0.1 MHz - 10 MHz Power Filter (>50 dB
attenuation). Simulation without effective
capacitance.

Input Filter for MCU voltage

Input Filter for RX path

Project: BioGAP WULPUS-pro shield

power.SchDoc Page 7 of 8

C:\Users\s-fre\Github\ethGitlab\sensei-wulpus-shield\hw\wulpus_pro_acq_pcb_dev_board\power.SchDoc

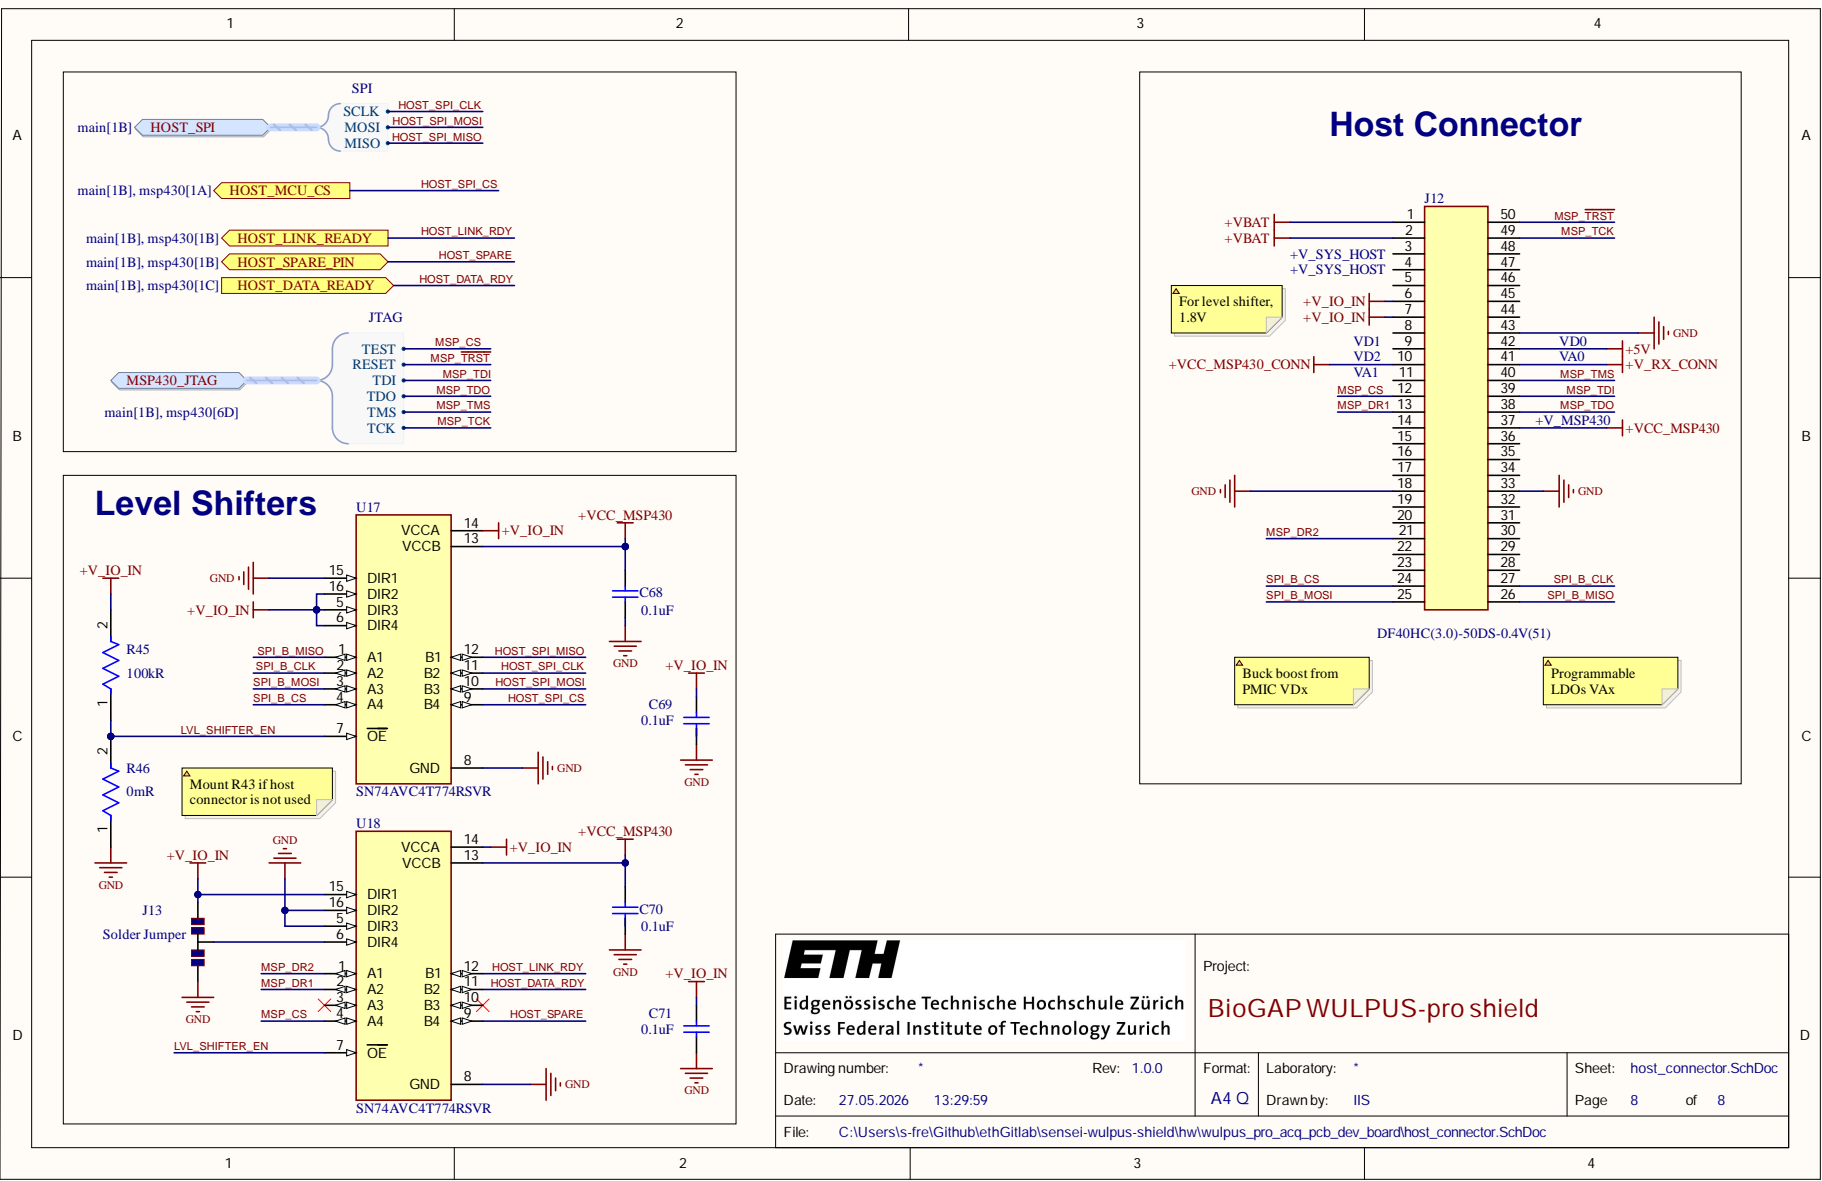
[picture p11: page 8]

1 6

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

Drawing num b e r: * R e v : 1. 0. 0 D a te : 27.05. 202 6 13:29 : 59 | Form a t: A 4 Q | Laborato ry : * Drawn by : I I S | Shee t: hos t_connec to r. S c h D o c Pag e 8 of 8

\s-fre\Github\ethGitlab\sensei-wulpus-shield\hw\wulpus
sers

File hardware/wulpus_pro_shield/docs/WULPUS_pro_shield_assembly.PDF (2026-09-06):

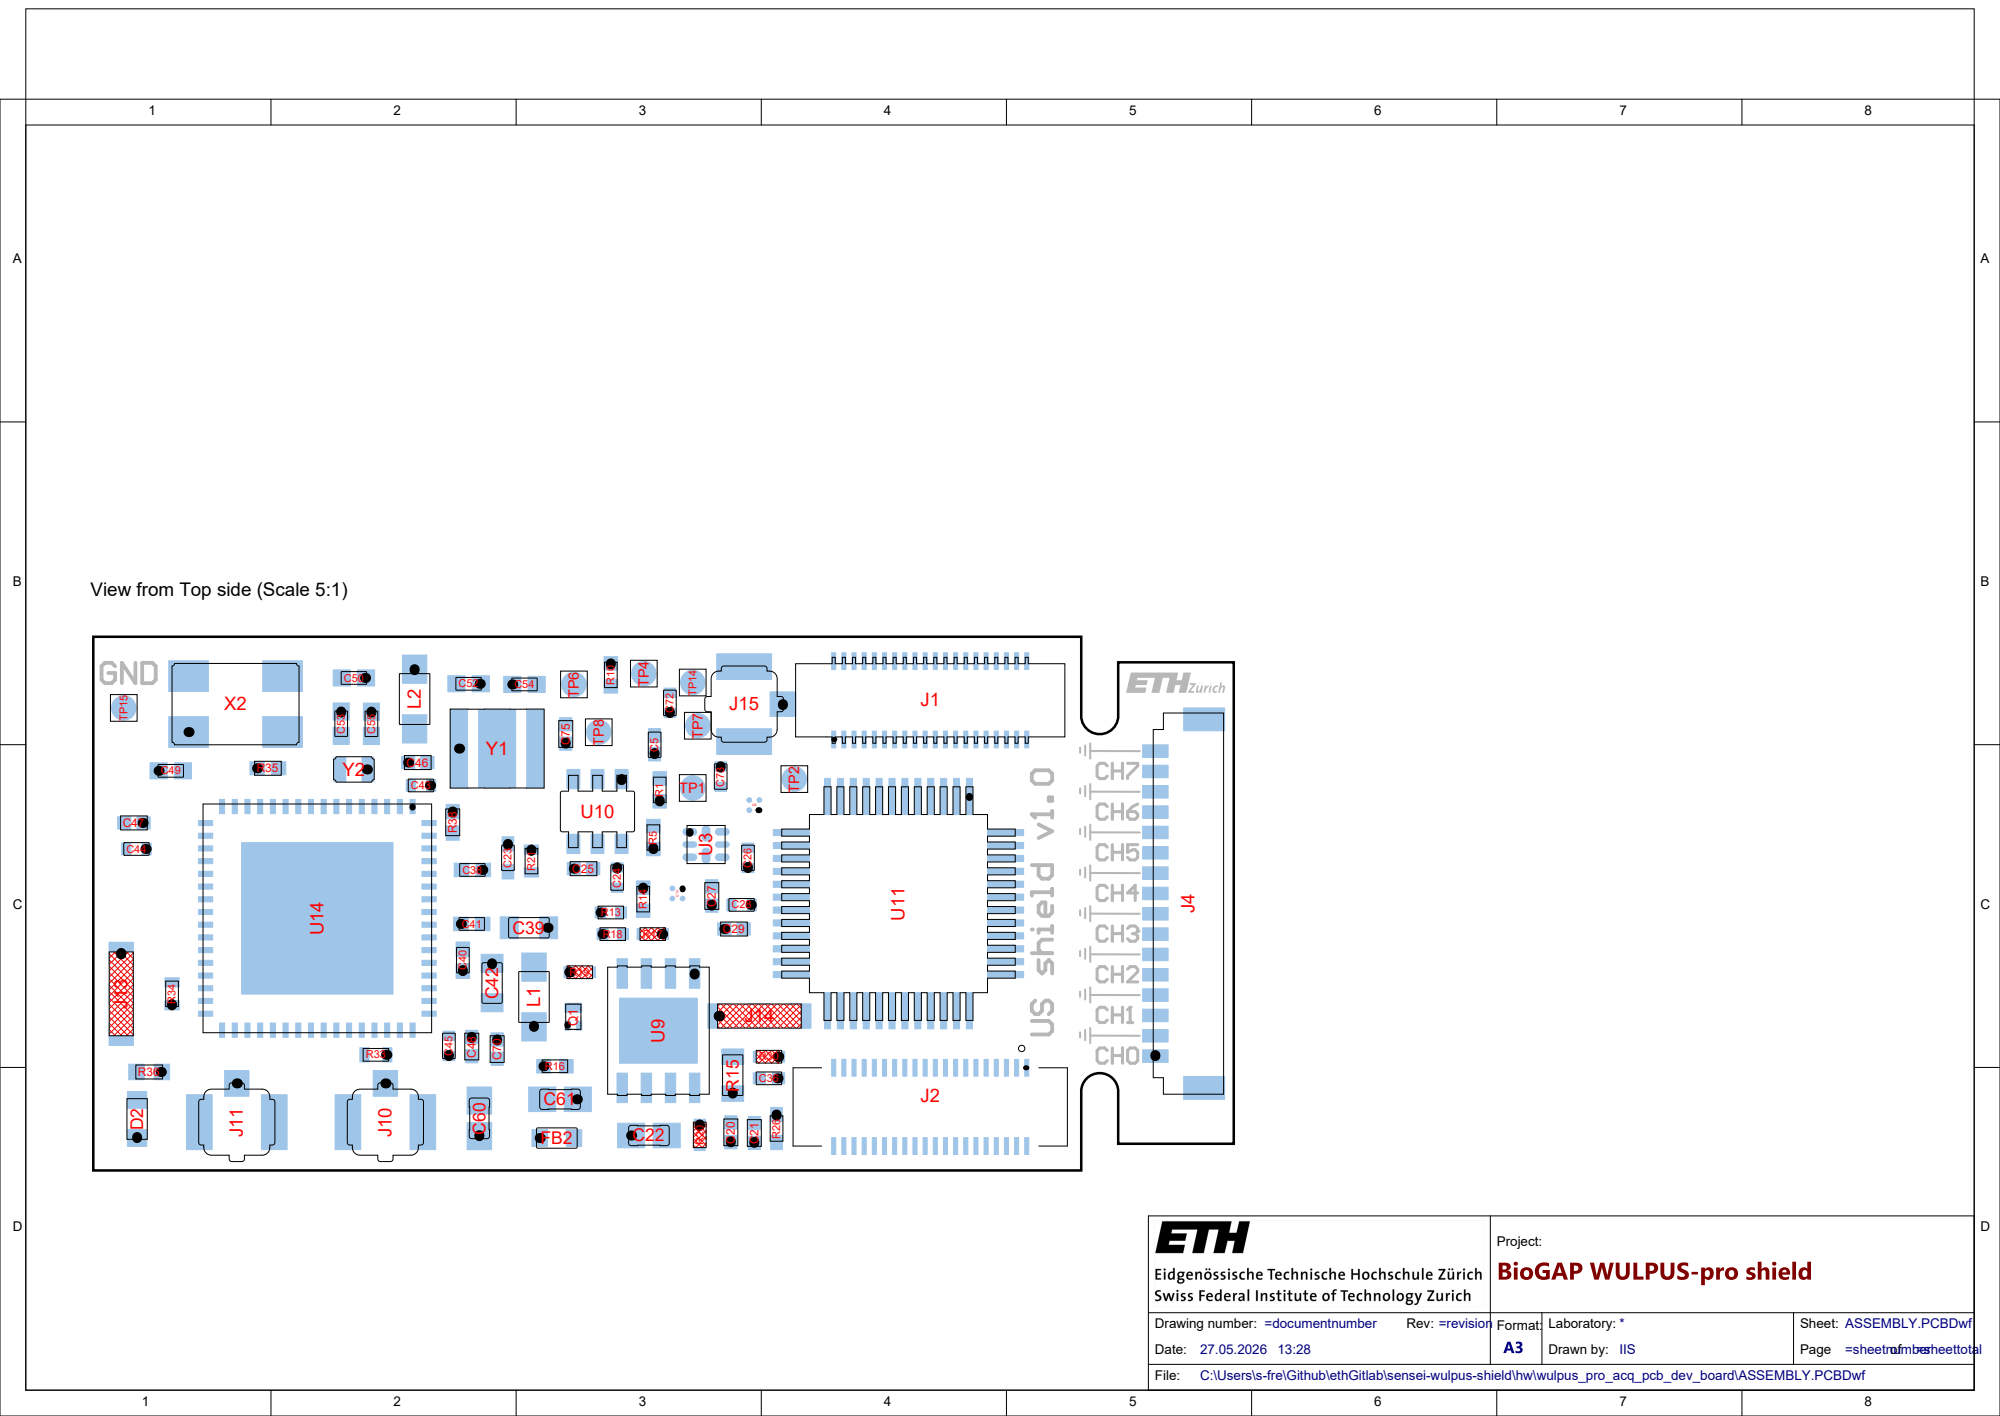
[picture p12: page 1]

View from Top side (Scale 5:1)

Project:

Drawing number: =documentnumber Rev: =revision Format: Date: 27.05.2026 13:28 | | Laboratory: * Drawn by: IIS | Sheet: ASSEMBLY.PCBDwf

Page =sheetnumber of =sheettotal

C:\Users\s-fre\Github\ethGitlab\sensei-wulpus-shield\hw\wulpus_pro_acq_pcb_dev_board\ASSEMBLY.PCBDwf

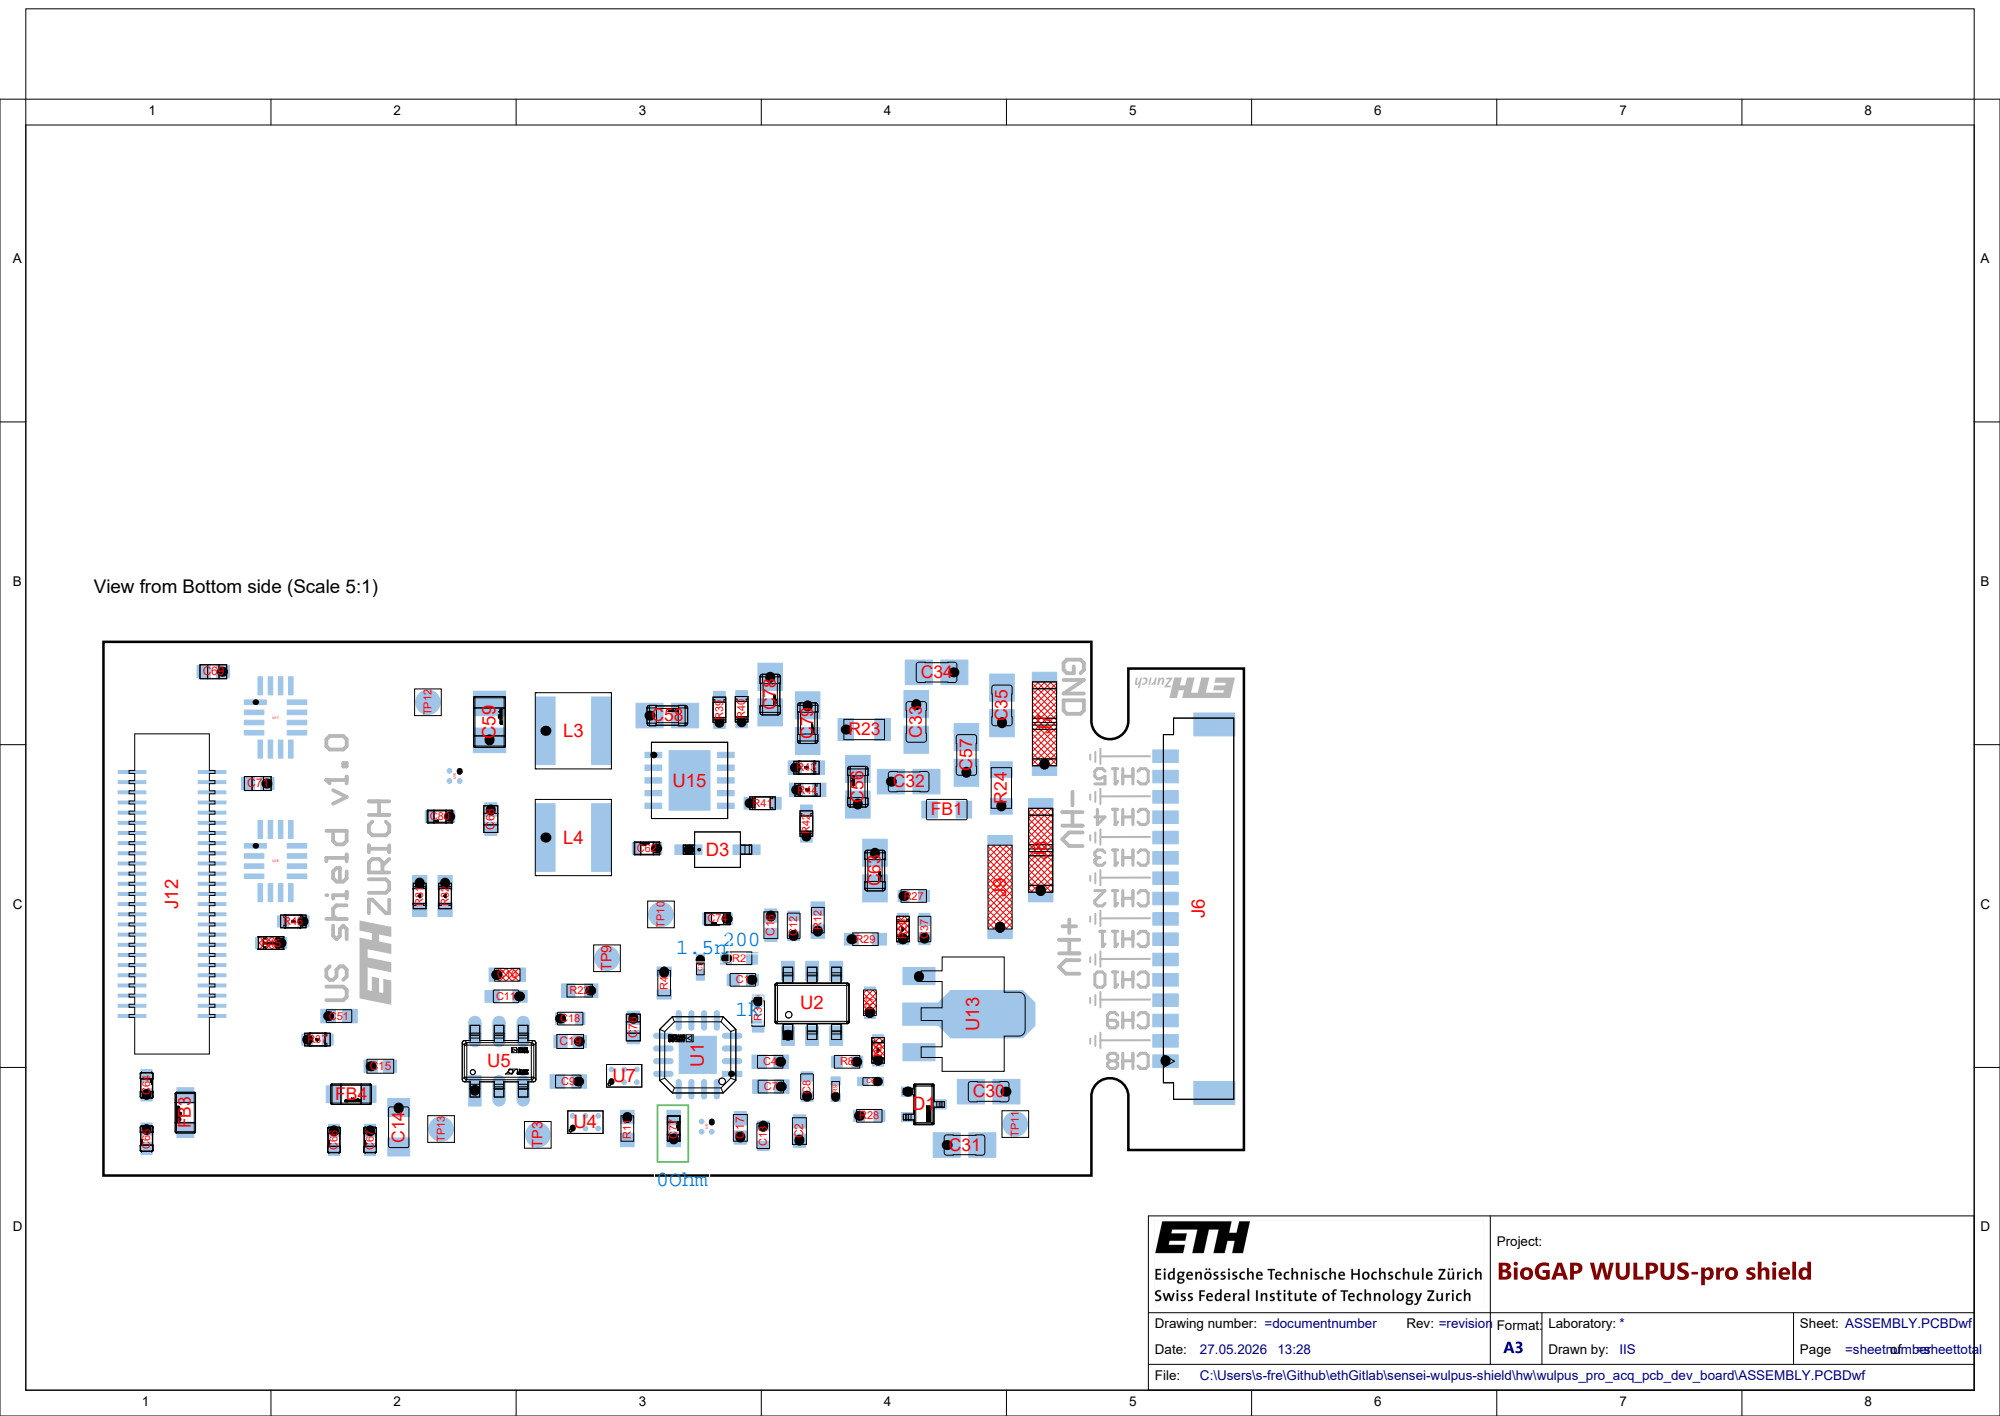
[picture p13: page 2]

View from Bottom side (Scale 5:1)

Sheet:
Page =sheetnumber of =sheettotal

C:\Users\s-fre\Github\ethGitlab\sensei-wulpus-shield\hw\wulpus_pro_acq_pcb_dev_board\ASSEMBLY.PCBDwf

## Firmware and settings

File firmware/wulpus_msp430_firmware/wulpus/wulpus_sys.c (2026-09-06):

/*
 * Copyright (C) 2025 ETH Zurich. All rights reserved.
 *
 * Author: Sergei Vostrikov, ETH Zurich
 *
 * Licensed under the Apache License, Version 2.0 (the "License");
 * you may not use this file except in compliance with the License.
 * You may obtain a copy of the License at
 *
 *      http://www.apache.org/licenses/LICENSE-2.0
 *
 * Unless required by applicable law or agreed to in writing, software
 * distributed under the License is distributed on an "AS IS" BASIS,
 * WITHOUT WARRANTIES OR CONDITIONS OF ANY KIND, either express or implied.
 * See the License for the specific language governing permissions and
 * limitations under the License.
 * 
 * SPDX-License-Identifier: Apache-2.0
 */

#include "wulpus_sys.h"


void getDefaultUsConfig(msp_config_t * msp_config)
{

    msp_config->pllOutFreq = HSPLL_OUT_80_MHZ;
    msp_config->xtalFreq = HSPLL_XTAL_FREQ_8_MHZ;
    msp_config->xtalType = HSPLL_XTAL_CERAMIC_RESONATOR;
    // No buffered xtal clock output
    msp_config->outEnPllXtal = false;


    msp_config->biasImp = BIAS_IMP_2950_OHM;
    msp_config->chargePumpMode = CHARGE_PUMP_NORMAL_MODE;

    msp_config->uupsBiasDelay = UUPS_BIAS_NO_DELAY;

    // Six time marks events (default values)
    msp_config->startPpgCnt = 2500;
    msp_config->turnOnAdcCnt = 25;
    msp_config->startPgaInBiasCnt = 25;
    msp_config->startAdcSamplCnt = 2514;
    msp_config->restartCaptCnt = 937;
    msp_config->captTimeoutCnt = 3750;

    // Extra time events (SW-managed)
    msp_config->startHvMuxRxCnt = 4000;
    msp_config->dcDcTurnOnTime = 1000;


    // Acquisition settings
    msp_config->overSamplRate = SDHS_OVER_SAMPL_RATE_10;
    msp_config->sampleSize = 400;
    msp_config->rxGain = PGA_GAIN_9_0_DB;
    msp_config->measPeriod = 32768;

    // VGA settings
    msp_config->vgaRcPrechargeCycles = 0;
    msp_config->vgaRcGainSlopeWiperCode = 256;

    // TX/RX configurations
    msp_config->txRxConfLen = 0;
//    msp_config->txConfigs[TX_RX_CONF_LEN_MAX];
//    msp_config->rxConfigs[TX_RX_CONF_LEN_MAX];

    // Pulser settins
    msp_config->driveStrength = PPG_NORMAL_DRIVE;

    msp_config->transFreq = 2250000; // Reserved, not used
    msp_config->pulseFreq = 2250000;
    msp_config->pulsesDutyCycle = 50; // 50 %
    msp_config->numPulses = 2;
    msp_config->numStopPulses = 0;
    msp_config->pulserPolarity = PPG_POLARITY_START_WITH_HIGH;
    msp_config->pulserPauseState = PPG_PAUSE_STATE_LOW;

    return;
}

// Extract Uss config from spi RX buffer
// Return 1 if config is valid
bool extractUsConfig(uint8_t * spi_rx, msp_config_t * msp_config)
{
    // Check start byte
    if (spi_rx[0] != START_BYTE_CONF_PACK)
        return 0;

    // Note: The MSP430 cannot access 2-byte words at odd addresses, so the CPU just ignores the lowest bit of word addresses.
    //Therefore, we do here some magic

    msp_config->dcDcTurnOnTime = READ_uint16(spi_rx + 1);
    msp_config->measPeriod     = READ_uint16(spi_rx + 3);
    msp_config->transFreq      = READ_uint32(spi_rx + 5); // Reserved, not used
    msp_config->pulseFreq      = READ_uint32(spi_rx + 9);
    msp_config->numPulses      = READ_uint8(spi_rx + 13);
    msp_config->overSamplRate  = (sdhs_over_sampl_rate_t)READ_uint16(spi_rx + 14);
    msp_config->sampleSize     = READ_uint16(spi_rx + 16);
    msp_config->rxGain         = READ_uint8(spi_rx + 18);
    msp_config->enEnvDetector  = READ_uint8(spi_rx + 19);
    msp_config->txRxConfLen    = READ_uint8(spi_rx + 20);

    if (msp_config->txRxConfLen > TX_RX_CONF_LEN_MAX)
        return 0;

    // Copy the TX RX configs
    uint8_t i;
    for (i = 0; i < (msp_config->txRxConfLen); i++)
    {
        msp_config->txConfigs[i] = READ_uint16(spi_rx + 21 + 4*i);
        msp_config->rxConfigs[i] = READ_uint16(spi_rx + 23 + 4*i);
    }

    uint8_t offset = 21 + 4*(msp_config->txRxConfLen);

    // Copy the data from the Advanced settings section
    msp_config->startHvMuxRxCnt         = READ_uint16(spi_rx + offset);
    msp_config->startPpgCnt             = READ_uint16(spi_rx + offset + 2);
    msp_config->turnOnAdcCnt            = READ_uint16(spi_rx + offset + 4);
    msp_config->startPgaInBiasCnt       = READ_uint16(spi_rx + offset + 6);
    msp_config->startAdcSamplCnt        = READ_uint16(spi_rx + offset + 8);
    msp_config->restartCaptCnt          = READ_uint16(spi_rx + offset + 10);
    msp_config->captTimeoutCnt          = READ_uint16(spi_rx + offset + 12);
    msp_config->vgaRcPrechargeCycles    = READ_uint16(spi_rx + offset + 14);
    msp_config->vgaRcGainSlopeWiperCode = READ_uint16(spi_rx + offset + 16);

    return 1;
}

// Check the first byte and check if restart should be done.
bool isRestartCondition(uint8_t * spi_rx)
{
    // Check for restart byte
    if (spi_rx[0] != START_BYTE_RESTART)
    {
        return 0;
    }

    return 1;
}
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
